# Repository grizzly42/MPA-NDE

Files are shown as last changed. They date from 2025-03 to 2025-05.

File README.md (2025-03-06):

# Antenna Deployment Mechanism

## Project Overview
This project is part of the **Nanosatellite Design and Electronics (MPA-NDE 24/25L)** course at **Brno University of Technology (BUT), Faculty of Electrical Engineering and Communication (FEEC)**. Our team is developing an **Antenna Deployment Mechanism** for a CubeSat-class nanosatellite.

## Purpose
The Antenna Deployment Mechanism (ADM) is designed to stow and deploy a flexible metal tape antenna reliably once the satellite reaches its operational orbit. The mechanism ensures the antenna remains secured during launch and deploys upon receiving an activation signal from the microcontroller unit (MCU).

## Key Features
- **Compact and Lightweight Design** – Optimized for CubeSat integration.
- **Reliable Deployment** – Ensures consistent antenna extension in space conditions.
- **Locking Mechanism** – Holds the antenna in place until deployment is required.
- **MCU Controlled Activation** – Deployment triggered via command.

## Components
- **Flexible Metal Tape Antenna**
- **Holding Mechanism (Damping System, Hinges, and Latch)**
- **Microcontroller (MCU) and Activation Circuitry**
- **Sensors for Deployment Verification**

## Block diagram
blokove_schema_navrhu

## SW (Dodělat podle skutečnosti)

```c
   DE2-PROJECT          
   ├── include         // Included file(s)
   │   └── timer.h
   ├── lib             // Libraries
   │   ├── gpio        // Your GPIO library
   │   │   ├── gpio.c
   │   │   └── gpio.h
   │   ├── oled        
   │   │   ├── oled.c
   │   │   ├── oled.h
   │   │   └── font.h
   │   ├── uart       
   │   │   ├── uart.c
   │   │   └── uart.h
   │   ├── twi       
   │   │   ├── twi.c
   │   │   └── twi.h
   │   ├── soil       
   │   │   ├── soil.c
   │   │   └── soil.h
   │   ├── controls       
   │   │   ├── controls.c
   │   │   └── controls.
   │   ├── HumTempSensor       
   │   │   ├── HumTempSensor.c
   │   │   └── HumTempSensor.h
   │   ├── rtc       
   │   │   ├── rtc.c
   │   │   └── rtc.h
   │   ├── display       
   │   │   ├── display.c
   │   │   └── display.h
   │   ├── buttons       
   │   │   ├── buttons.c
   │   │   └── buttons.h
   │   ├── pot       
   │   │   ├── pot.c
   │   │   └── pot.h
   │   └── light       
   │       ├── light.c
   │       └── light.h
   ├── src             // Source file(s)
   │   └── main.c
   ├── test            // No need this
   └── platformio.ini  // Project Configuration File
   ```

## Team
This project is developed by students of **MPA-NDE 24/25L** at BUT FEEC as part of a nanosatellite technology research initiative.

## Future Work
- Prototype development and testing.
- Thermal and mechanical stress analysis.
- Integration with satellite subsystems.

## License
This project is for academic and research purposes under the Nanosatellite Design and Electronics course at BUT.

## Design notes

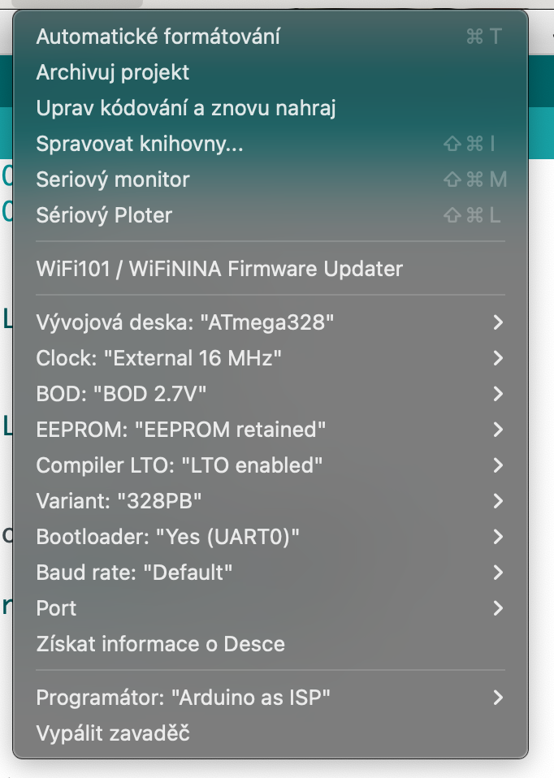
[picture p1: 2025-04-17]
NASTAVENI ARDUINO IDE.png

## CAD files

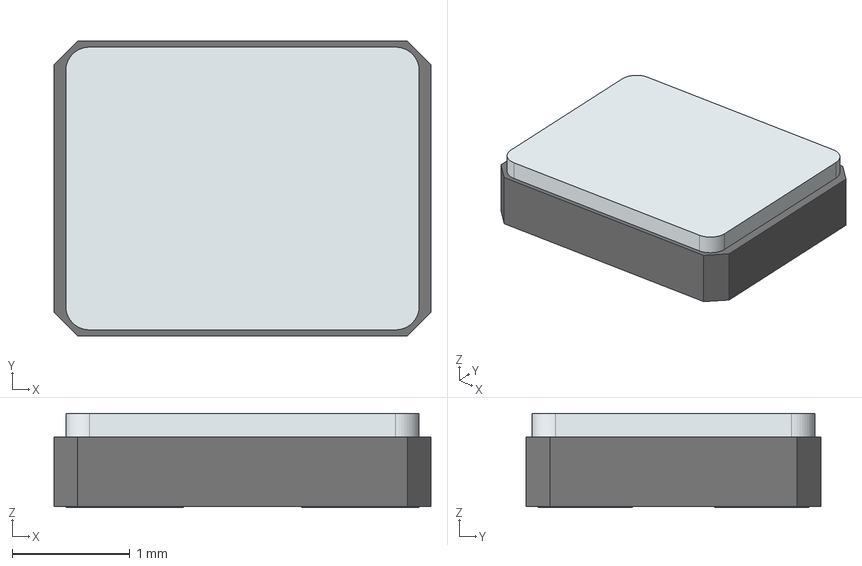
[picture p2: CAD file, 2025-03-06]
kicad_project_libs/abracom/3D/ABM8-16.000MHZ-7-1-U-T.stp
3.20 x 2.50 x 0.8 mm
solidBody
solidLid
solidTerminal

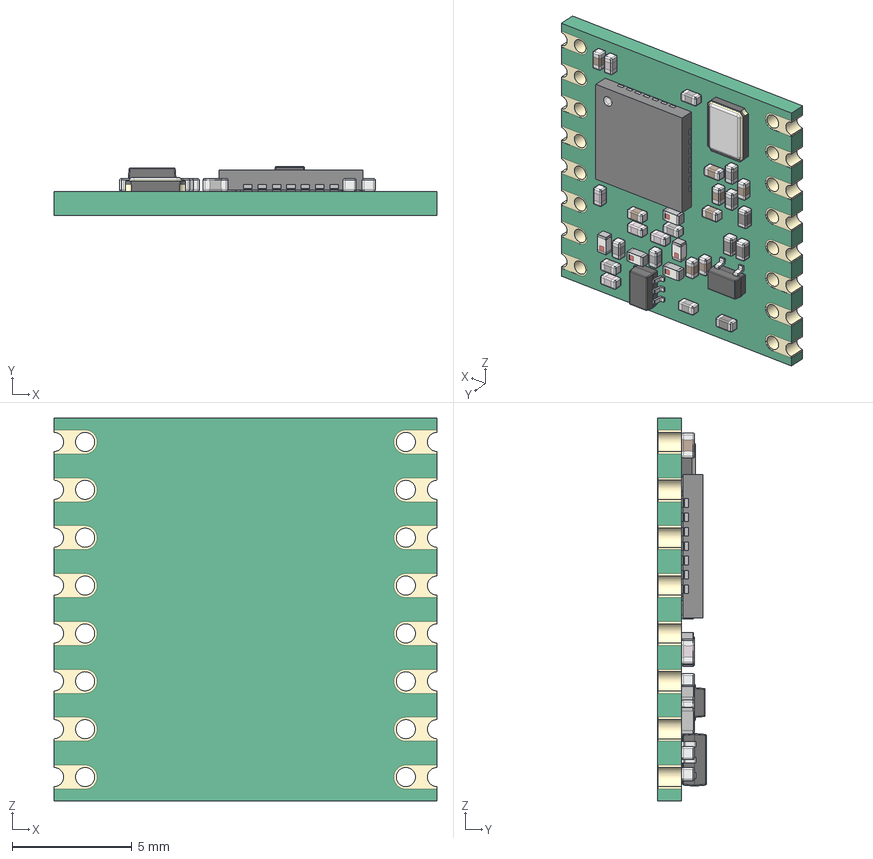
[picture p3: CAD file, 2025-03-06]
kicad_project_libs/hoperf95/RFM95 LoRa v15.step
16.0 x 2.04 x 16.0 mm
QFN 28
SMD Crystal
CAP 0403 x 8
CAP Ceramic 0403 x 8
Res 0403 x 4
CAP ML 0403 x 5
SOT-323
Inductor SMD 0403 x 5
SOT-363

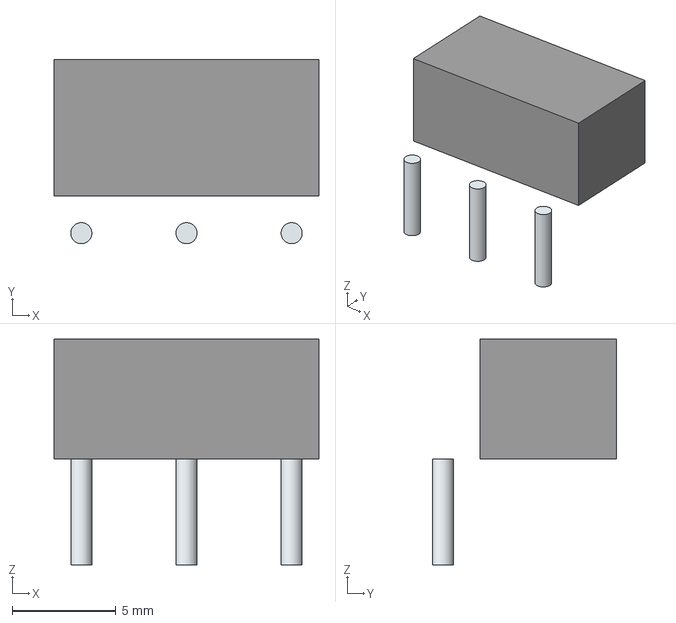
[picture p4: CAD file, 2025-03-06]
kicad_project_libs/moment_switch/ZMA00A080L04RC.stp
12.8 x 8.91 x 10.9 mm
Leads

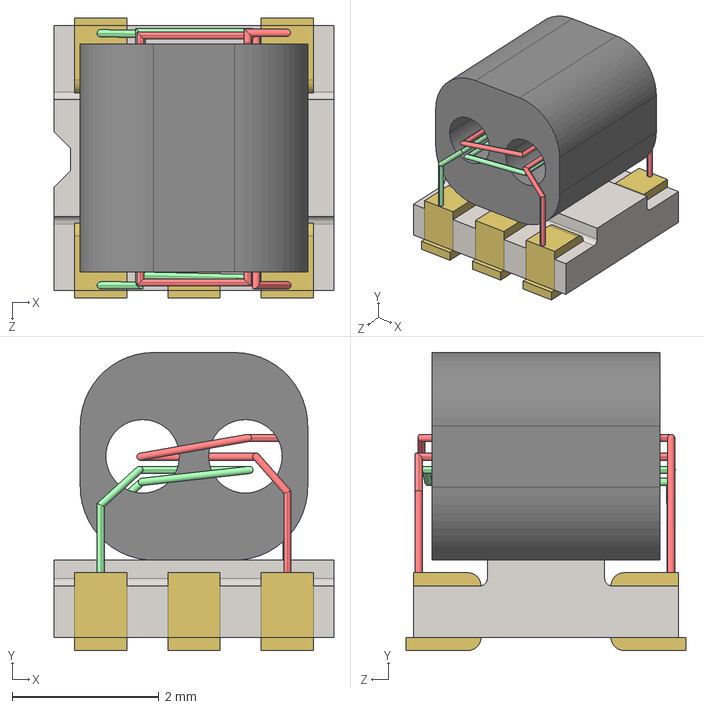
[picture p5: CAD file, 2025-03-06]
kicad_project_libs/TC1-15+/TC1-1-13M.stp
3.81 x 4.06 x 3.81 mm

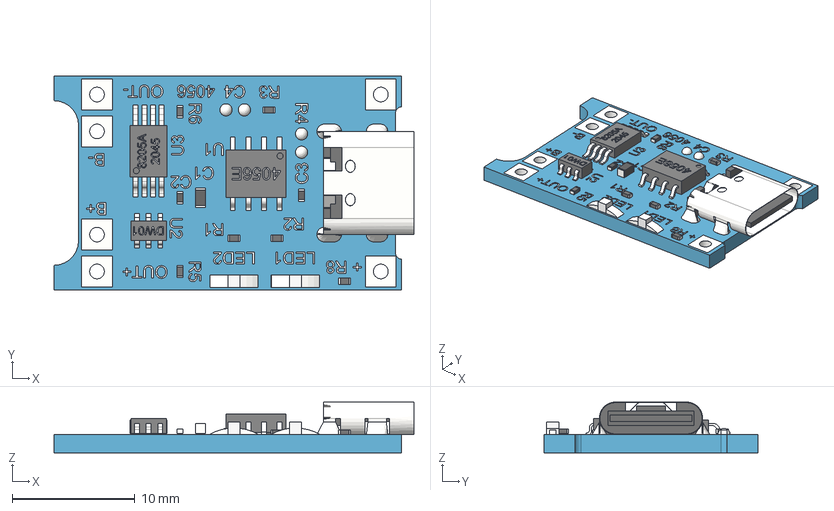
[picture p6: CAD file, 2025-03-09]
kicad_project_libs/TP4056_charging_module/TP4056_Charging_Module_Type_C.step
29.3 x 17.4 x 4.14 mm
board
USB_Type_C_Connector
8205A_2045
DW01-P
small1005_smd_resistor x 2
small1005_smd_resistor (1)
small1005_smd_capacitor
smd_capacitor
SOP-8_4056E
solder_dot_round
solder_dot_round (1)
solder_dot_round (2)
solder_dot_round (3)
small1005_smd_capacitor (1)
LED2
LED2 (1)
small1005_smd_resistor (2)
small1005_smd_resistor (4) x 2
soldering

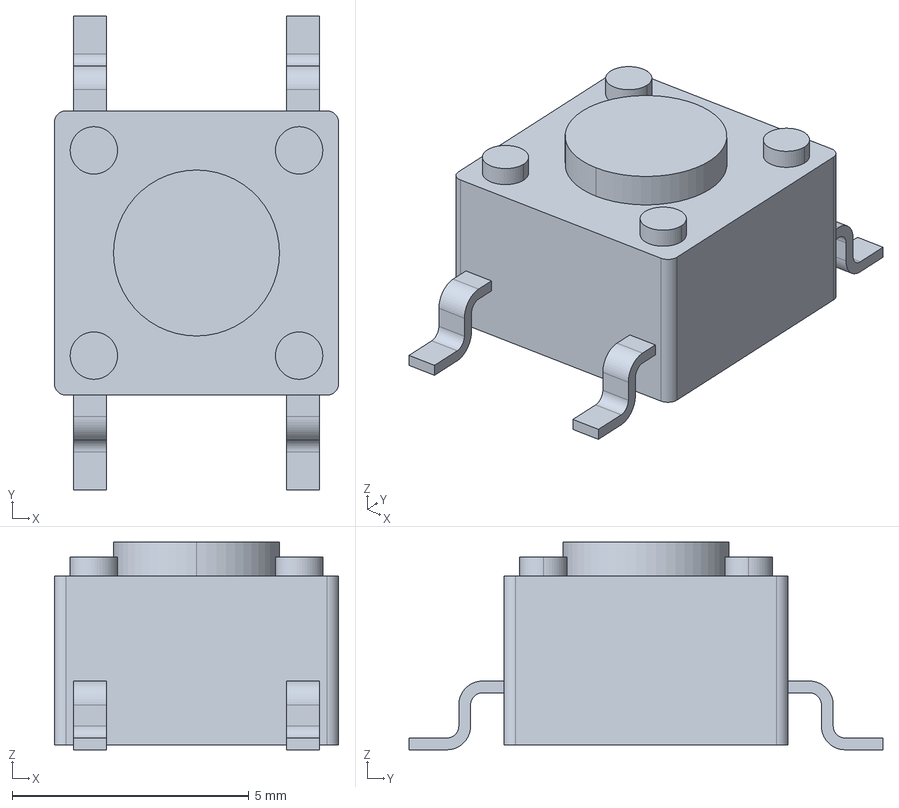
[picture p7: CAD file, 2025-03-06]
kicad_project_libs/push_btn/1571527-2.stp
6.00 x 10.0 x 4.38 mm

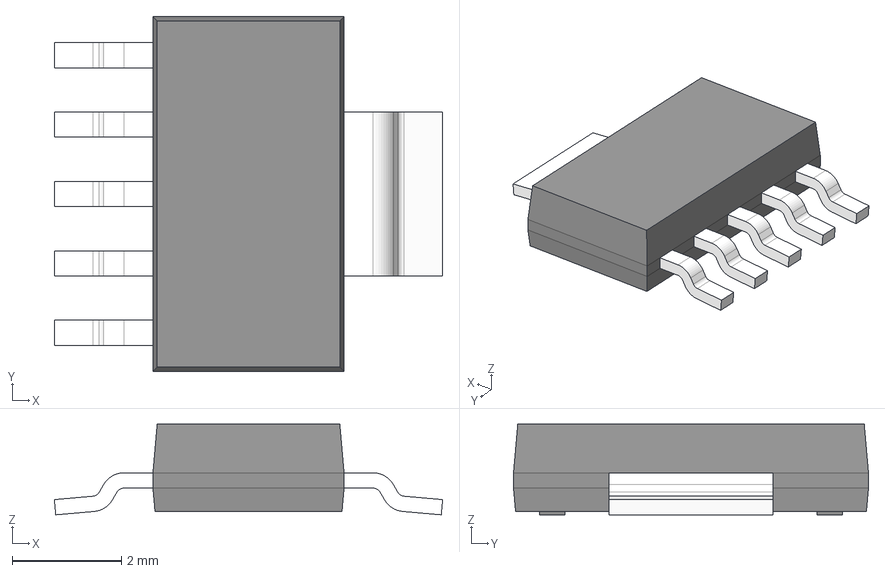
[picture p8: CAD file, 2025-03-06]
kicad_project_libs/TPS795/TPS79501DCQ.stp
7.11 x 6.50 x 1.66 mm
LEAD x 5
LEAD_WIDE

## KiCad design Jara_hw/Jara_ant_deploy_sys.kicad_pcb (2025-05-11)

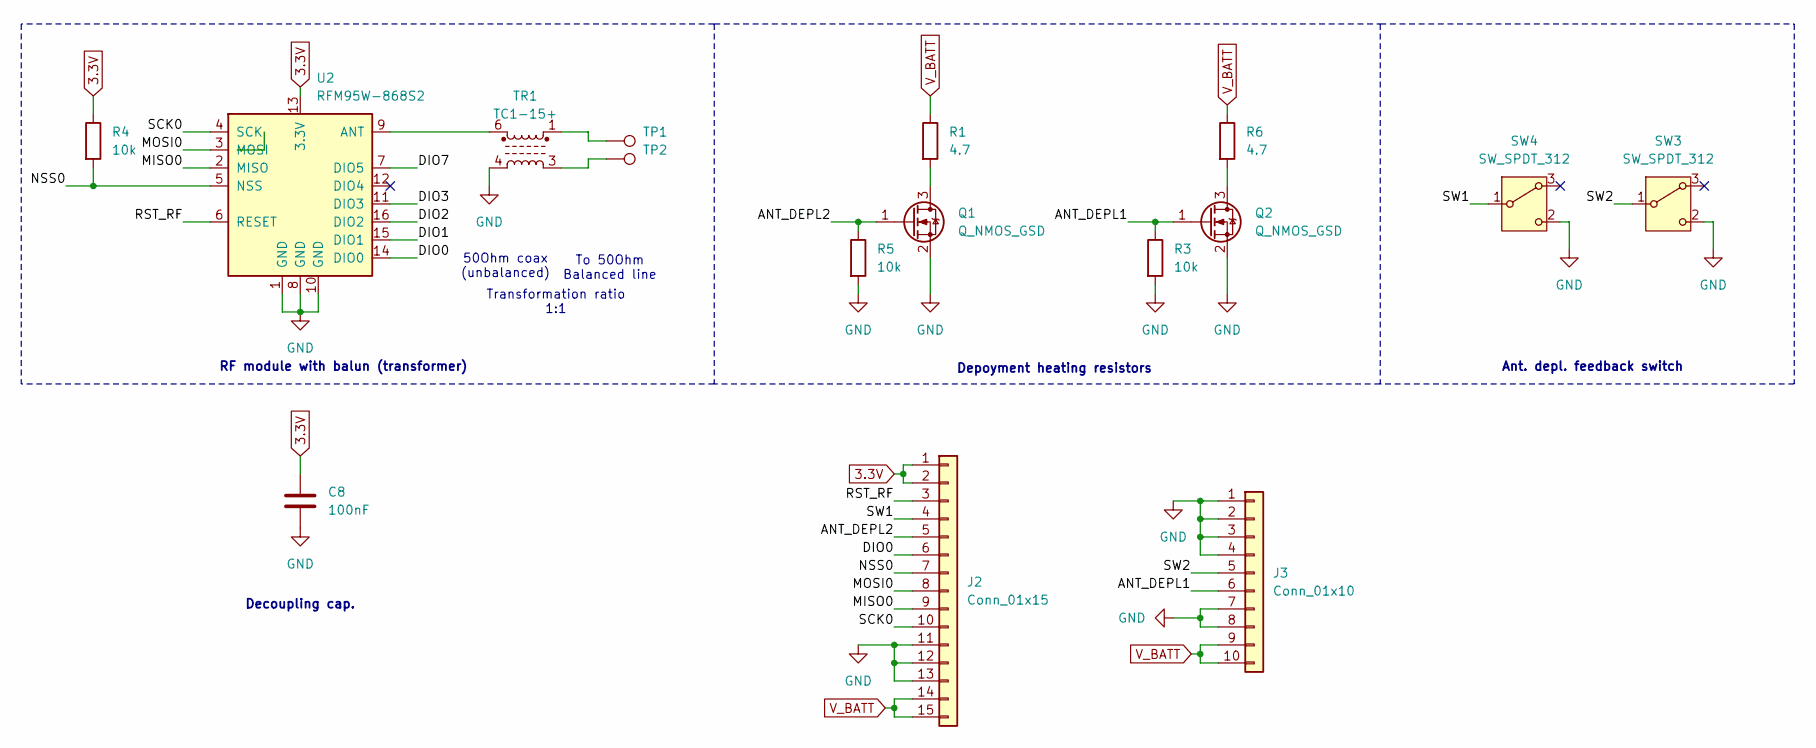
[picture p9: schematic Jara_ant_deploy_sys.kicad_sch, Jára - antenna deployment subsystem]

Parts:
C8: 100nF; C_0805_2012Metric
J2: Conn_01x15; PinHeader_1x15_P2.54mm_Vertical
J3: Conn_01x10; PinHeader_1x10_P2.54mm_Vertical
Q1, Q2: Q_NMOS_GSD; SOT-23
R1, R6: 4.7; R_0805_2012Metric
R3, R4, R5: 10k; R_0805_2012Metric
SW3, SW4: SW_SPDT_312; ZMA00A080L04RC
TP1, TP2: TestPoint_Pad_1.5x1.5mm
TR1: TC1-15+; Transformer_MiniCircuits_AT224-1A
U2: RFM95W-868S2; HOPERF_RFM9XW_SMD

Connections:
3.3V: C8.1, J2.1, J2.2, R4.1, U2.13 (3.3V)
/ANT_DEPL1: J3.6, Q2.1 (G), R3.1
/ANT_DEPL2: J2.5, Q1.1 (G), R5.1
/DIO0: J2.6, U2.14 (DIO0)
/DIO1: U2.15 (DIO1)
/DIO2: U2.16 (DIO2)
/DIO3: U2.11 (DIO3)
/DIO7: U2.7 (DIO5)
/MISO0: J2.9, U2.2 (MISO)
/MOSI0: J2.8, U2.3 (MOSI)
/NSS0: J2.7, R4.2, U2.5 (NSS)
/RST_RF: J2.3, U2.6 (RESET)
/SCK0: J2.10, U2.4 (SCK)
/SW1: J2.4, SW4.1 (B)
/SW2: J3.5, SW3.1 (B)
GND: C8.2, J2.11, J2.12, J2.13, J3.1, J3.2, J3.3, J3.4, J3.7, J3.8, Q1.2 (S), Q2.2 (S), R3.2, R5.2, SW3.2 (C), SW4.2 (C), TR1.4, U2.1 (GND), U2.8 (GND), U2.10 (GND)
unnamed: Q1.3 (D), R1.2
unnamed: Q2.3 (D), R6.2
unnamed: TP1.1, TR1.1
unnamed: TP2.1, TR1.3
unnamed: TR1.6, U2.9 (ANT)
V_BATT: J2.14, J2.15, J3.9, J3.10, R1.1, R6.1

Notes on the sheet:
RF module with balun (transformer)
Decoupling cap.
50Ohm coax (unbalanced)
To 50Ohm Balanced line
Ant. depl. feedback switch
Depoyment heating resistors
Transformation ratio 1:1

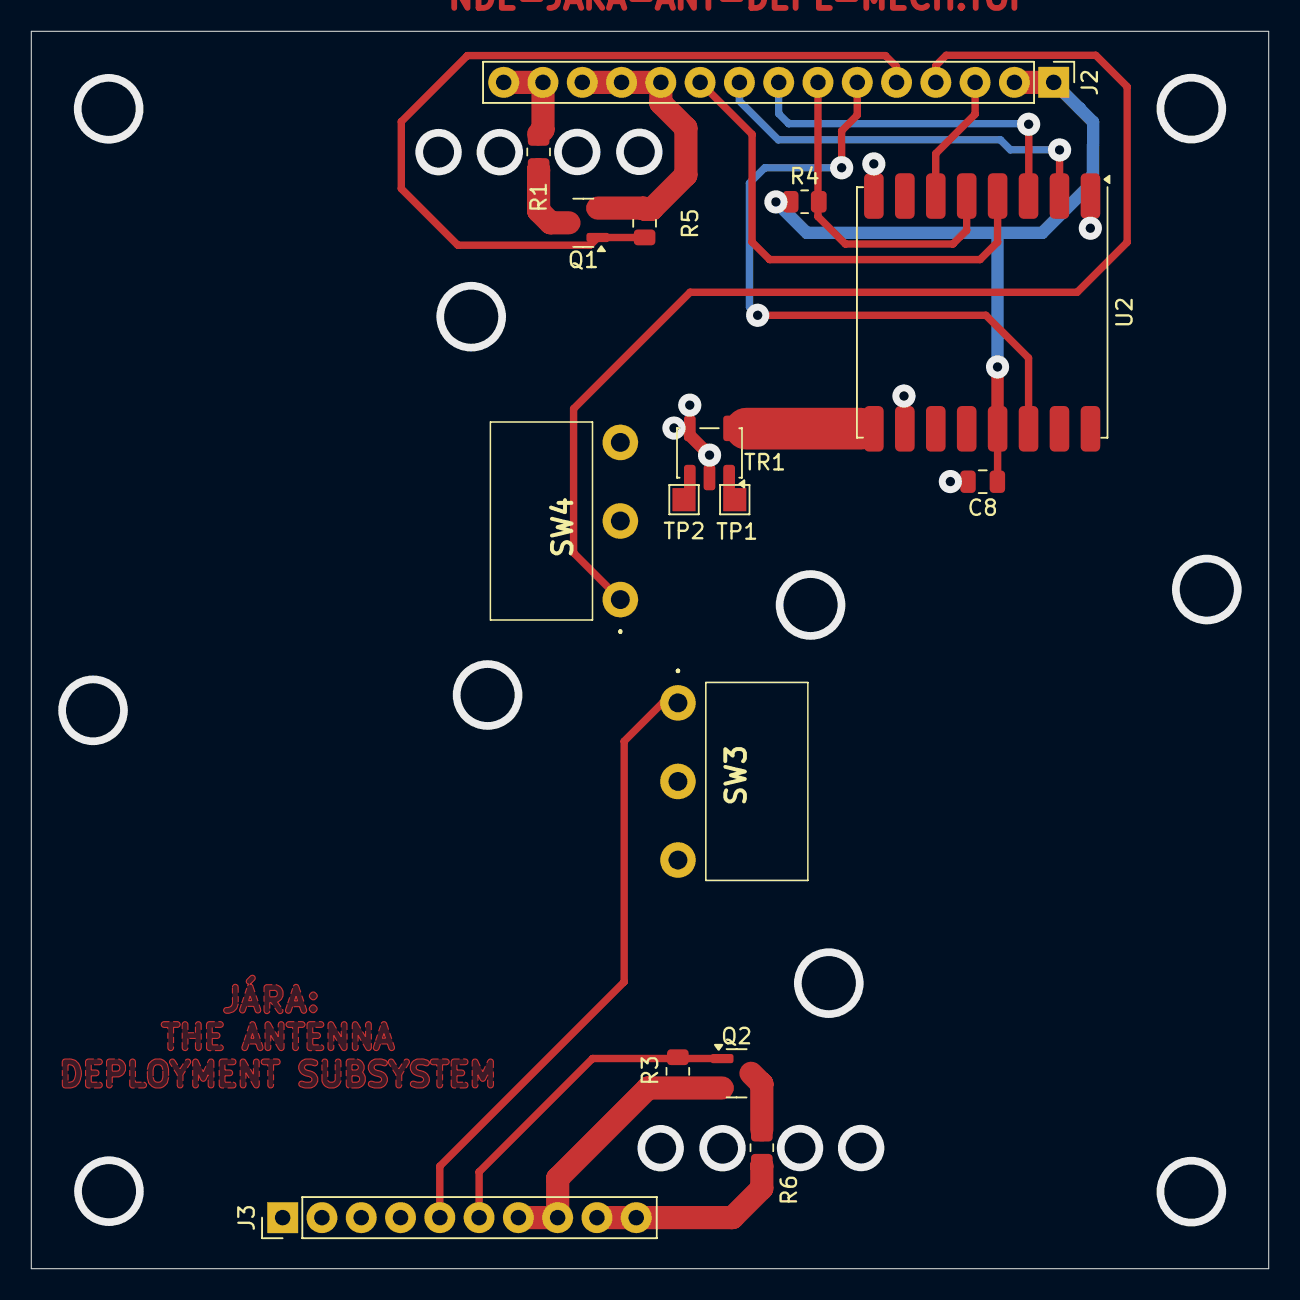
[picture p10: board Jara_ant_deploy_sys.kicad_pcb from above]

Board: 2 copper layers, 80.0 x 80.0 mm, 16 parts (0 on the bottom side), 18 nets.

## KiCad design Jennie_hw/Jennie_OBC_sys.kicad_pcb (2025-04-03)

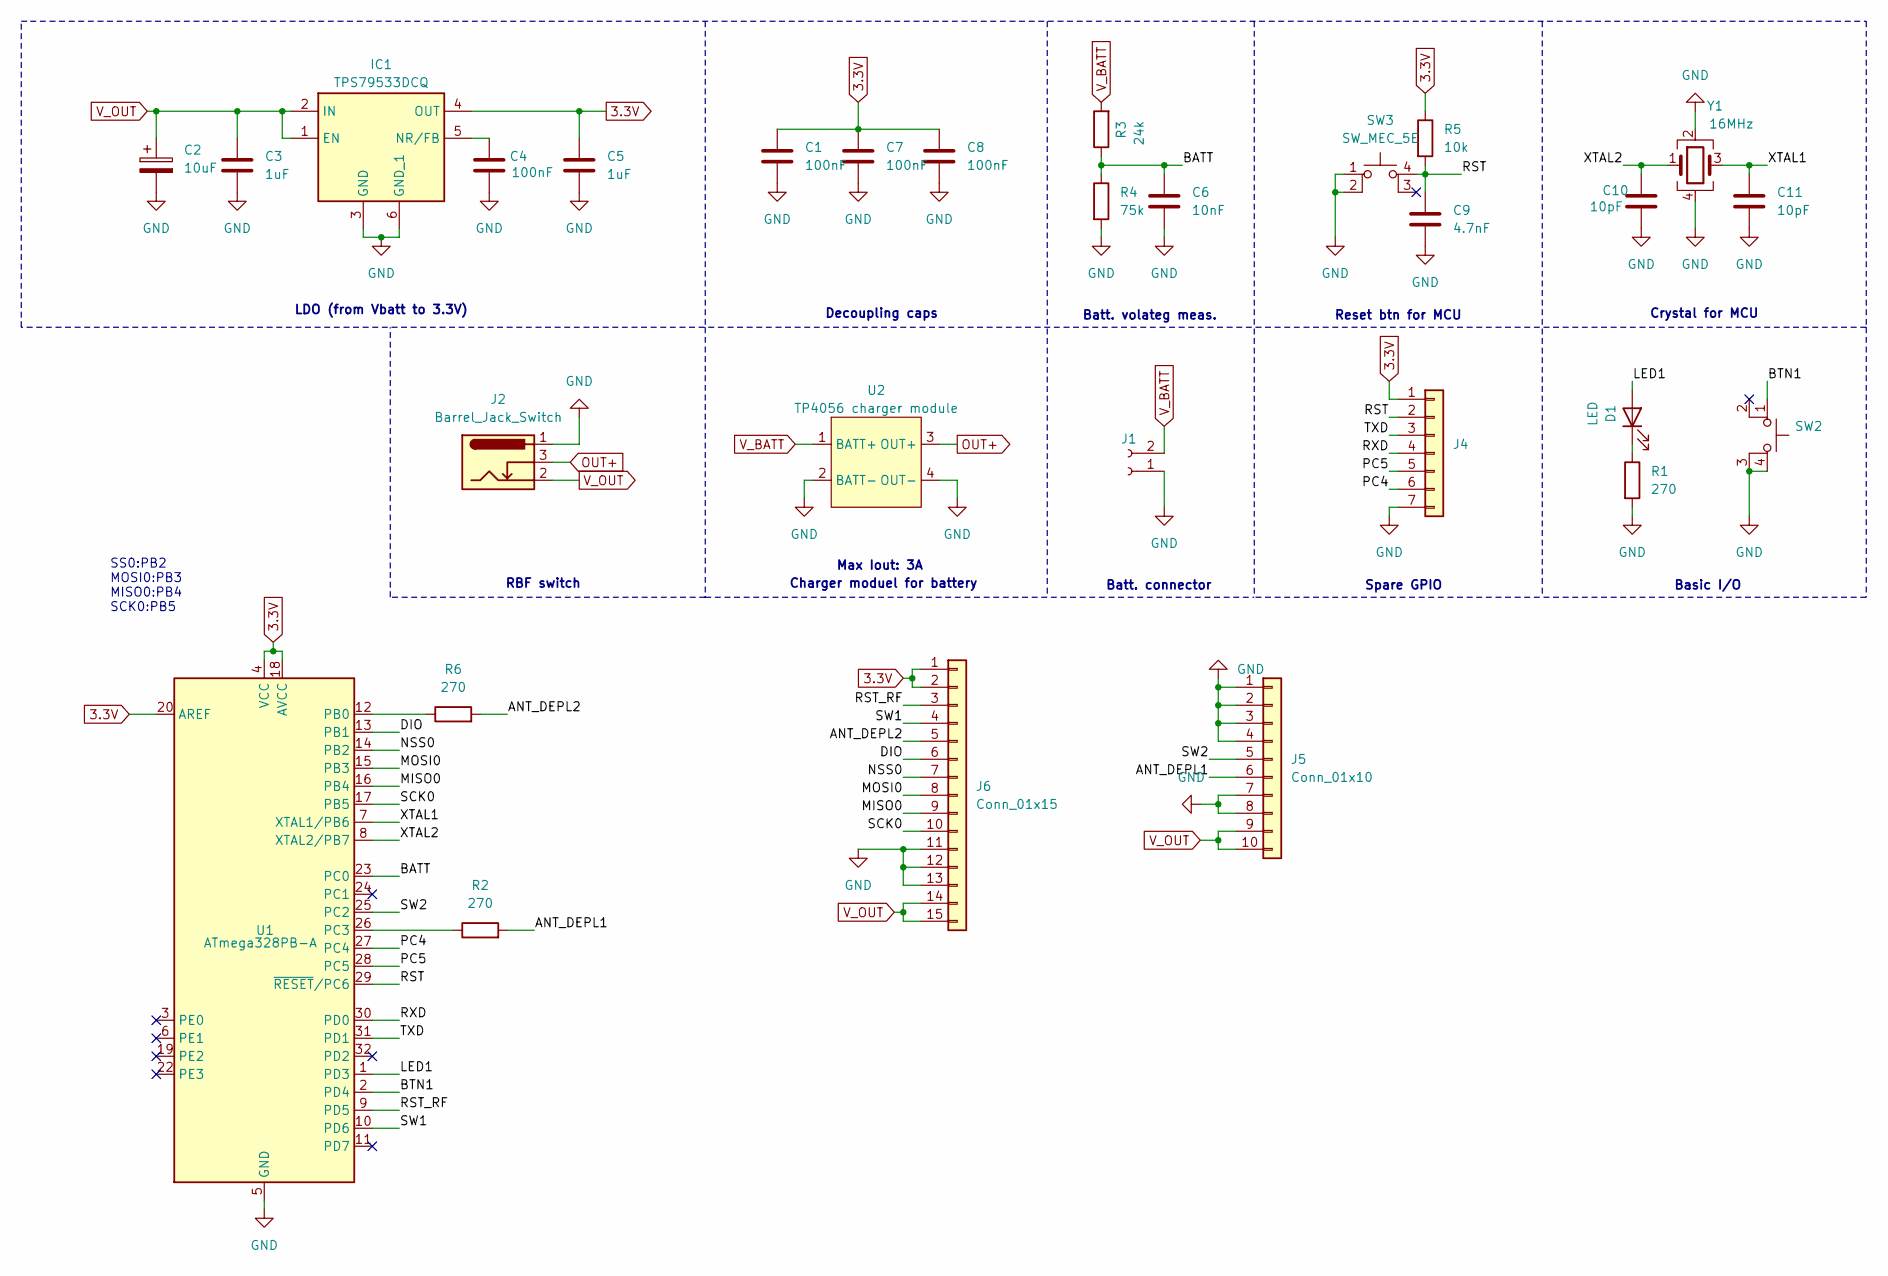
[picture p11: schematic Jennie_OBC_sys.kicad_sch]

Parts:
C1, C4, C7, C8: 100nF; C_0805_2012Metric
C2: 10uF; CP_Radial_D5.0mm_P2.50mm
C3, C5: 1uF; C_0805_2012Metric
C6: 10nF; C_0805_2012Metric
C9: 4.7nF; C_0805_2012Metric
C10, C11: 10pF; C_0805_2012Metric
D1: LED; LED_0805_2012Metric
IC1: TPS79533DCQ; SOT-223-6; Mouser Part Number 595-TPS79533DCQ
J1: PinHeader_1x02_P2.54mm_Vertical
J2: Barrel_Jack_Switch; BarrelJack_Horizontal
J4: PinHeader_1x07_P2.54mm_Vertical
J5: Conn_01x10; PinHeader_1x10_P2.54mm_Vertical
J6: Conn_01x15; PinHeader_1x15_P2.54mm_Vertical
R1, R2, R6: 270; R_0805_2012Metric
R3: 24k; R_0805_2012Metric
R4: 75k; R_0805_2012Metric
R5: 10k; R_0805_2012Metric
SW2: 15715272
SW3: SW_MEC_5E; 15715272
U1: ATmega328PB-A; TQFP-32_7x7mm_P0.8mm
U2: TP4056 charger module; TP4056_module
Y1: 16MHz; Crystal_SMD_3225-4Pin_3.2x2.5mm

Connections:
3.3V: C1.1, C5.1, C7.1, C8.1, IC1.4 (OUT), J4.1, J6.1, J6.2, R5.1, U1.4 (VCC), U1.18 (AVCC), U1.20 (AREF)
/ANT_DEPL1: J5.6, R2.2
/ANT_DEPL2: J6.5, R6.2
/BATT: C6.1, R3.1, R4.1, U1.23 (PC0)
/BTN1: SW2.1, U1.2 (PD4)
/DIO: J6.6, U1.13 (PB1)
/LED1: D1.2 (A), U1.1 (PD3)
/MISO0: J6.9, U1.16 (PB4)
/MOSI0: J6.8, U1.15 (PB3)
/NSS0: J6.7, U1.14 (PB2)
/PC4: J4.6, U1.27 (PC4)
/PC5: J4.5, U1.28 (PC5)
/RST: C9.1, J4.2, R5.2, SW3.4 (A), U1.29 (~RESET/PC6)
/RST_RF: J6.3, U1.9 (PD5)
/RXD: J4.4, U1.30 (PD0)
/SCK0: J6.10, U1.17 (PB5)
/SW1: J6.4, U1.10 (PD6)
/SW2: J5.5, U1.25 (PC2)
/TXD: J4.3, U1.31 (PD1)
/XTAL1: C11.1, U1.7 (XTAL1/PB6), Y1.3
/XTAL2: C10.1, U1.8 (XTAL2/PB7), Y1.1
GND: C1.2, C2.2, C3.2, C4.2, C5.2, C6.2, C7.2, C8.2, C9.2, C10.2, C11.2, IC1.3 (GND), IC1.6 (GND_1), J1.1, J2.1, J4.7, J5.1, J5.2, J5.3, J5.4, J5.7, J5.8, J6.11, J6.12, J6.13, R1.2, R4.2, SW2.3 (K), SW2.4 (A), SW3.1, SW3.2, U1.5 (GND), U1.21 (GND), U2.2 (BATT-), U2.4 (OUT-), Y1.2, Y1.4
unnamed: D1.1 (K), R1.1
unnamed: C4.1, IC1.5 (NR/FB)
unnamed: R6.1, U1.12 (PB0)
unnamed: R2.1, U1.26 (PC3)
OUT+: J2.3, U2.3 (OUT+)
V_BATT: J1.2, R3.2, U2.1 (BATT+)
V_OUT: C2.1, C3.1, IC1.1 (EN), IC1.2 (IN), J2.2, J5.9, J5.10, J6.14, J6.15

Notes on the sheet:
Batt. connector
Decoupling caps
Basic I/O
Batt. volateg meas.
Charger moduel for battery
Spare GPIO
Max Iout: 3A
RBF switch
Crystal for MCU
Reset btn for MCU
SS0:PB2 MOSI0:PB3 MISO0:PB4 SCK0:PB5
LDO (from Vbatt to 3.3V)

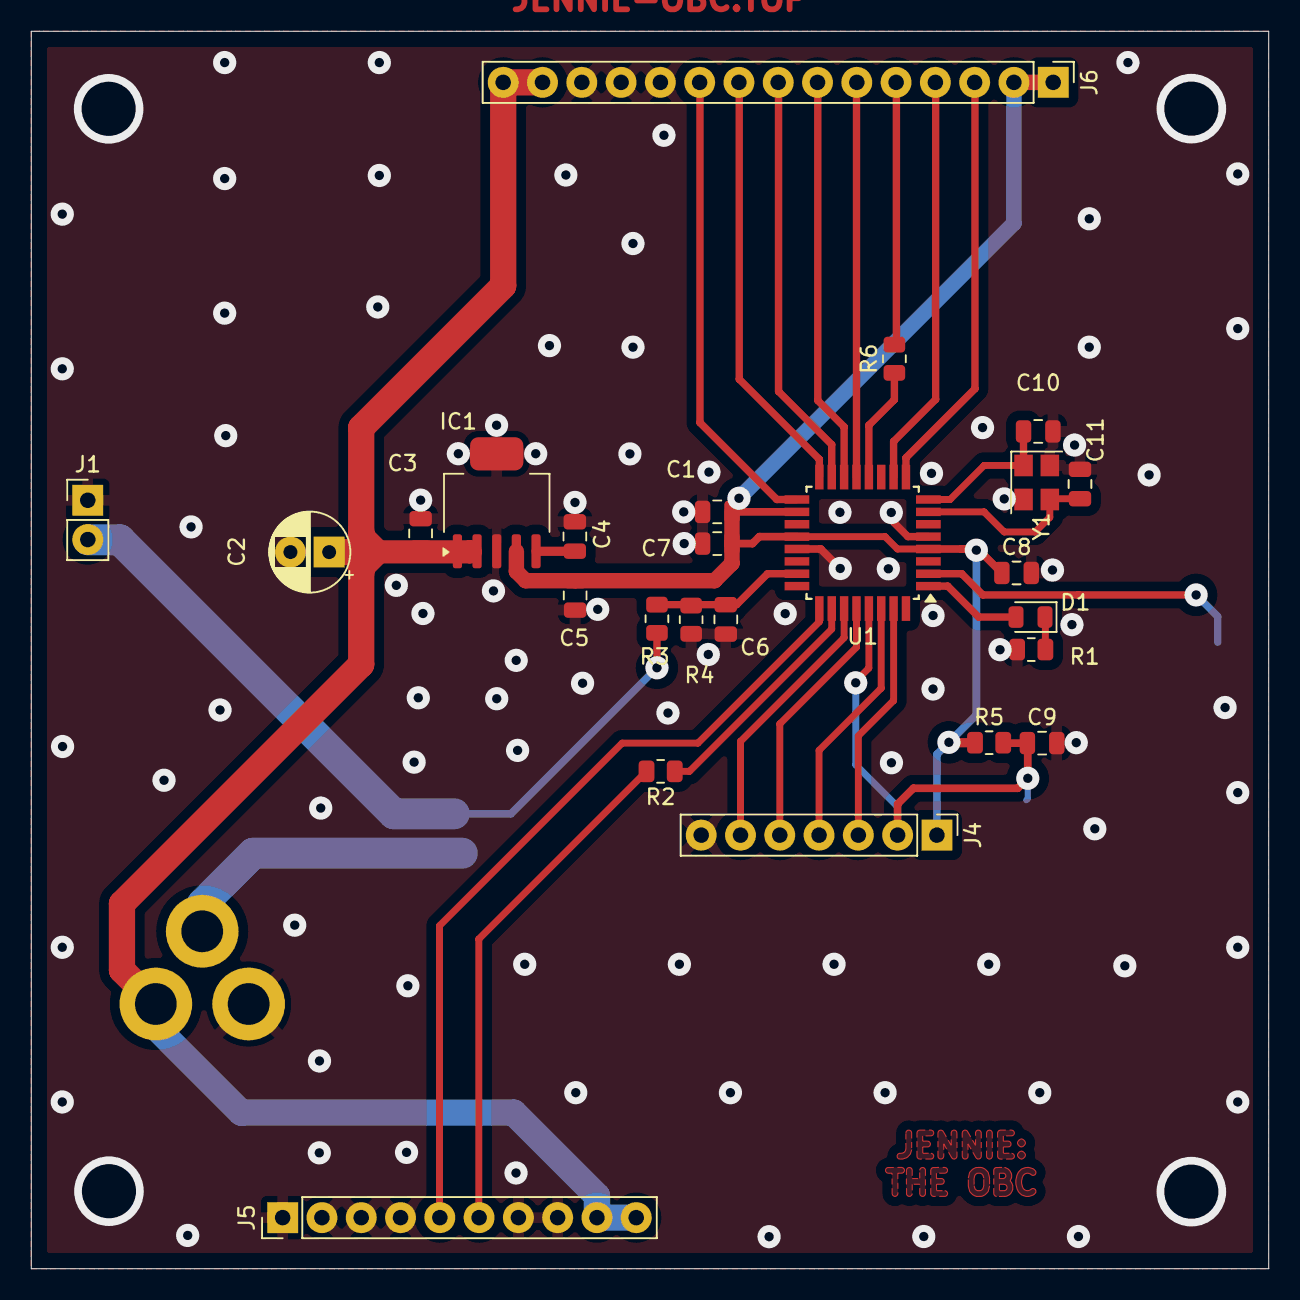
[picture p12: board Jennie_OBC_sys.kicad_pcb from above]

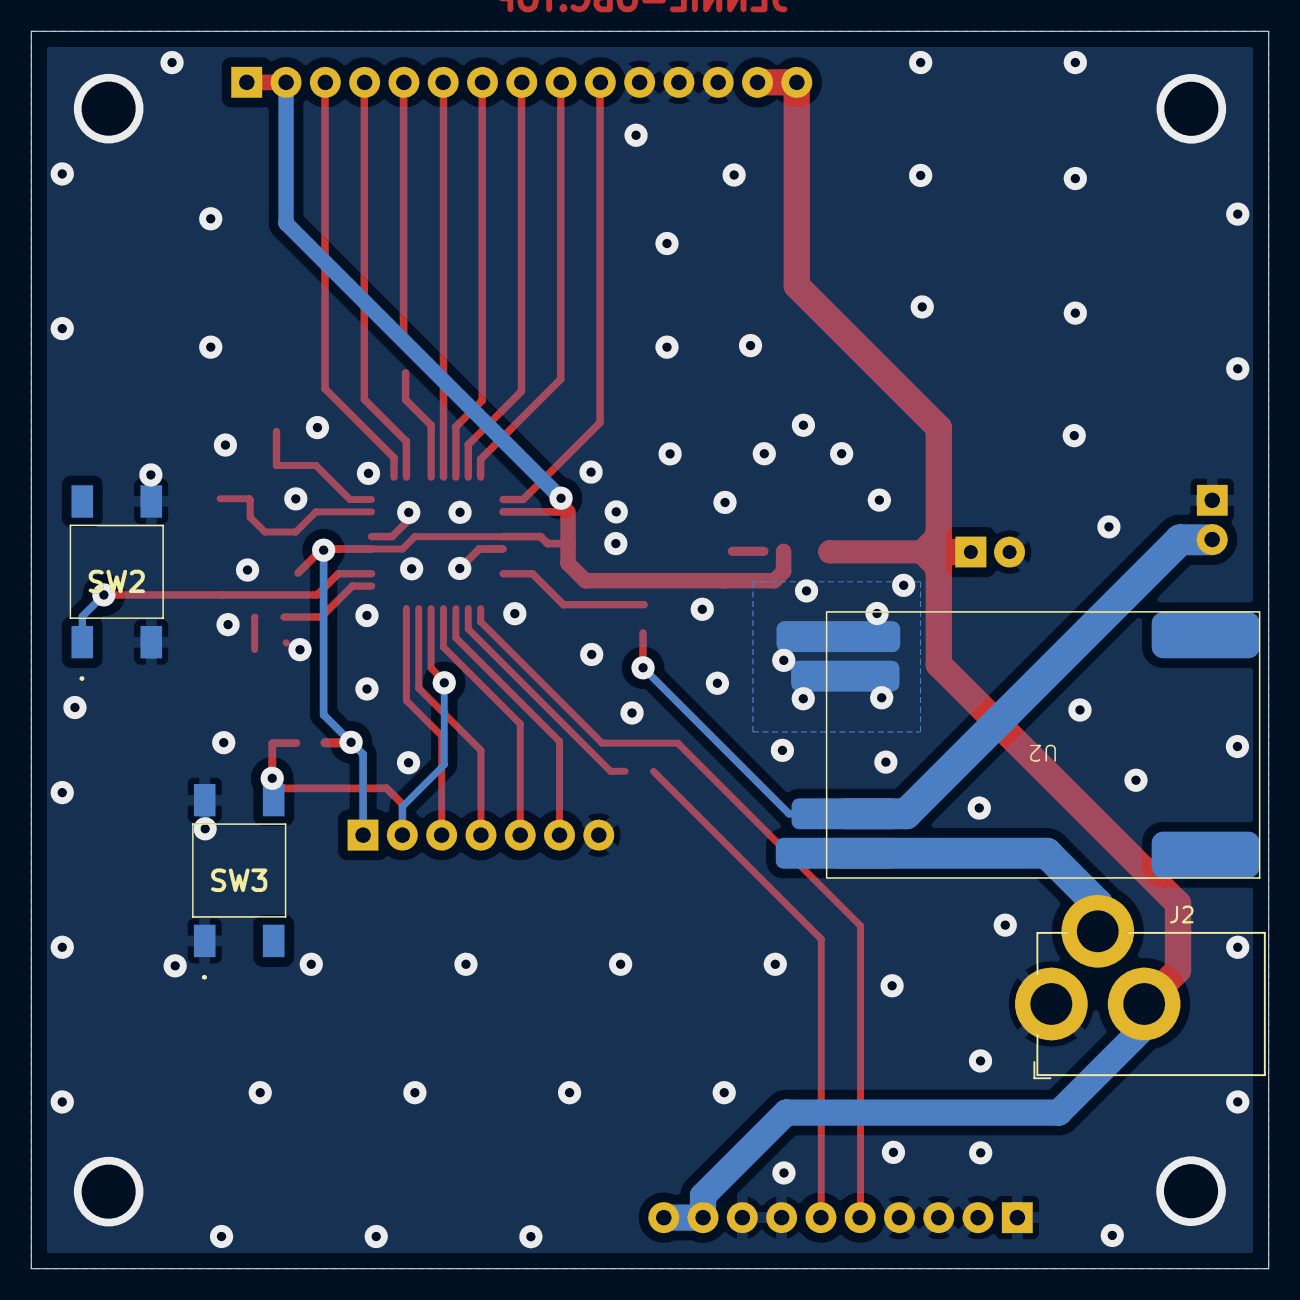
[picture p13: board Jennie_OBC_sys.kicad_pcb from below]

Board: 2 copper layers, 80.0 x 80.0 mm, 29 parts (4 on the bottom side), 29 nets.

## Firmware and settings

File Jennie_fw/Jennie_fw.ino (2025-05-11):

#include <SPI.h>
#include <LoRa.h>

#include "pakety.h"

#define LED PD3        // LED pro výstup
#define BTN PD4        // Tlačítko pro aktivaci

#define SWITCH1_PIN 16  // Koncový spínač 1
#define OUTPUT1_PIN 17  // Výstup pro spínač 1

#define SWITCH2_PIN 6  // Koncový spínač 2
#define OUTPUT2_PIN 8  // Výstup pro spínač 2

#define PROG_EN PC4
#define JUST_GND PC5

#define TIMEOUT 5000  // Timeout v ms

#define BW 125E3
#define TXPWR 10 // in dBm
#define SF 12 //spreading factor

bool start_depl = false;
unsigned long timeout_state = 0;
bool output1_active = false;
bool output2_active = false;

const float referenceVoltage = 3.3;   // nebo 5.0, podle toho, co přivádíš na AREF
const float voltageDividerRatio = 72.0 / (24.0 + 72.0);

int counter = 0;
int p_counter = 0;

void setup() {
  Serial.begin(9600);

  pinMode(SWITCH1_PIN, INPUT_PULLUP);
  pinMode(SWITCH2_PIN, INPUT_PULLUP);

  pinMode(OUTPUT1_PIN, OUTPUT);
  pinMode(OUTPUT2_PIN, OUTPUT);

  pinMode(LED, OUTPUT);
  pinMode(BTN, INPUT_PULLUP);

  pinMode(PROG_EN, INPUT_PULLUP);
  pinMode(JUST_GND, OUTPUT);
  digitalWrite(JUST_GND, LOW);

  digitalWrite(LED, LOW);
  digitalWrite(OUTPUT1_PIN, LOW);
  digitalWrite(OUTPUT2_PIN, LOW);

  if (!LoRa.begin(868E6)) {
    Serial.println("Starting LoRa failed!");
    while (1);
  } else {
    Serial.println("Starting LoRa succeed");
  }

  // Bezpečnostní pojistka, pokud nechceme deployment
  while (digitalRead(PROG_EN) == LOW) {
    Serial.println("Programming wire connected");
    delay(1000);
  }


  LoRa.setSignalBandwidth(BW);
  LoRa.setTxPower(TXPWR);
  LoRa.setSpreadingFactor(SF);

  // Signalizace zapnutí
  digitalWrite(LED, HIGH);
  delay(1000);
  digitalWrite(LED, LOW);
  Serial.println("setup ok");

}

void loop() {
  delay(30);
  Serial.println("loop start");
  if (digitalRead(BTN) == LOW || !start_depl) {
    start_depl = true;
    Serial.println("Tlačítko stisknuto, start!");

    // Aktivace výstupů
    digitalWrite(LED, HIGH);
    //digitalWrite(OUTPUT1_PIN, HIGH);
    //digitalWrite(OUTPUT2_PIN, HIGH);

    output1_active = true;
    output2_active = true;
  }

  if (start_depl) {
    Serial.println("Depl start");
    // Kontrola výstupu 1
    if (output1_active) {
      if (digitalRead(SWITCH1_PIN) == HIGH) {
        digitalWrite(OUTPUT1_PIN, LOW);
        output1_active = false;
        Serial.println("OUTPUT 1 OFF");
      }
    }

    // Kontrola výstupu 2
    if (output2_active) {
      if (digitalRead(SWITCH2_PIN) == HIGH) {
        digitalWrite(OUTPUT2_PIN, LOW);
        output2_active = false;
        Serial.println("OUTPUT 2 OFF");
      }
    }
    if (!output1_active && !output2_active) {
      //start_depl = false;

      delay(5000);

      int raw = analogRead(PC0); // nebo A0
      float voltageADC = (raw / 1023.0) * referenceVoltage;
      float batteryVoltage = voltageADC / voltageDividerRatio;

      digitalWrite(LED, LOW);
      Serial.println("Sekvence dokončena.");

      Serial.print("Sending packet: ");
      Serial.println(counter);

      // send packet
      LoRa.beginPacket();

      LoRa.print("pct n. ");
      LoRa.println(counter);

      LoRa.print("VBatt: ");
      LoRa.println(batteryVoltage);

      LoRa.println(pakety[p_counter]);

      LoRa.endPacket();

      if (p_counter >= packet_count - 1) {
        p_counter = 0;
      } else {
        p_counter++;
      }
      counter++;
    }
  }
}

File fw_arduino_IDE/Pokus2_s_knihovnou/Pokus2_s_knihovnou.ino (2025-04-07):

#include <SPI.h>
#include <LoRa.h>

int counter = 0;

#define BW 125E3 
#define TXPWR 10 // in dBm
#define SF 12 //spreading factor

void setup() {
  Serial.begin(9600);
  while (!Serial);

  Serial.println("LoRa Sender");

  if (!LoRa.begin(868E6)) {
    Serial.println("Starting LoRa failed!");
    while (1);
  }
  LoRa.setSignalBandwidth(BW);
  LoRa.setTxPower(TXPWR);
  LoRa.setSpreadingFactor(SF);
}

void loop() {
  Serial.print("Sending packet: ");
  Serial.println(counter);

  // send packet
  LoRa.beginPacket();
  LoRa.print("hello ");
  LoRa.print(counter);
  LoRa.endPacket();

  counter++;

  delay(5000);
}

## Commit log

2025-03-06 Jara and Jennie subsystems HW added, not finished yet
    [1571527-2.stp, ABM8-16.000MHZ-7-1-U-T.stp, Jara_ant_deploy_sys.kicad_pcb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]
2025-03-06 Jennie and Jára PCBs prepared for manufacturing(?)
    [Jara_ant_deploy_sys.kicad_pcb, Jennie_OBC_sys.kicad_pcb, ZMA00A080L04RC.stp]
2025-03-06 3D models of Jára and Jennie PCBs added
    [Jara_ant_deploy_sys.kicad_pcb, Jennie_OBC_sys.kicad_pcb, TC1-1-13M.stp]
2025-03-09 Push buttons moved to bottom side, STEP model of TP4056 added
    [Jennie_OBC_sys.kicad_pcb, TP4056_Charging_Module_Type_C.step]
2025-03-11 remove before start switch added
    [Jennie_OBC_sys.kicad_pcb, Jennie_OBC_sys.kicad_sch]
2025-03-11 cleaning up the schematics
    [Jara_ant_deploy_sys.kicad_sch]
2025-03-13 IBOM added
    [Jara_ant_deploy_sys.kicad_pcb, Jennie_OBC_sys.kicad_pcb]
2025-04-03 small fix of small routing error on Jennie PCB (V_batt routed to different pins on pinheader to maintain compatibility with Jára pinheader)
    [Jara_ant_deploy_sys.kicad_pcb, Jennie_OBC_sys.kicad_pcb, Jennie_OBC_sys.kicad_sch]
2025-04-17 lora jede někde ve fw je issue
    [Blink_Jennie.ino, test_LoRa.ino]
2025-05-11 Minor changes in PCB design
2025-05-11 DIO7 changed to DIO0 on Jára PCB to be compatibile with the LoRa Arduino library
    [Jara_ant_deploy_sys.kicad_pcb, Jara_ant_deploy_sys.kicad_sch]
2025-05-11 antenna model
